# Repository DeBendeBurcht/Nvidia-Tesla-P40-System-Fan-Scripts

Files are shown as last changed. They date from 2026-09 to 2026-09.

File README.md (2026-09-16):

# 🌀 Nvidia Tesla P40 — System Fan Scripts

Control a **power-injected 9377 blower** (e.g. Delta BFB1012EH) from inside a Linux VM, through Proxmox, onto a motherboard `SYS_FAN` header.

Built for a **pasthrough NVIDIA Tesla P40 24GB** with a custom low-restriction shroud. Tuned and verified on **Proxmox VE** + **Debian 12**. The same ideas may work on other KVM setups with minor path tweaks.

---

> ⚠️ **Heads-up**  
> This repository was written with the help of AI. It is **not actively maintained**.  
> There is no support channel, no guaranteed compatibility matrix, and no promise that a future Proxmox / kernel / nvidia update will keep working without changes.  
>  
> That said — I'm proud of what this does on my box. Use it, fork it, break it, fix it. You own the risk on your own hardware.

---

## 🚨 Critical warnings (read before you touch hardware)

### 1. Set a **flat** BIOS fan curve first
If the host script is stopped, crashed, or not started yet, the motherboard reclaims the header. A normal BIOS “smart” curve will fight your last PWM write and can produce wild RPM swings.

**Do this in UEFI/BIOS before relying on the daemon:**

- Open the fan / hardware monitor page for the header you will use (`SYS_FAN2` in this project).
- Set a **flat fixed percentage** curve — not temperature-linked steps.  
  Example that works here: **20%** steady.
- Save and exit.

That way “script not running” = quiet, predictable airflow, not a roulette wheel.

### 2. Pick the **correct** fan header — wrong header can brick your calm
The host script writes directly to `pwmN` on the Super I/O chip (IT8689 via `it87`).

| Wrong move | What happens |
|---|---|
| `FAN_HEADER` points at CPU_FAN / a different SYS_FAN | You fight the BIOS or another controller on that channel |
| Two writers on the same `pwmN` (BIOS auto + script, or two scripts) | **Race condition** on the register — RPM hunting, odd ACPI behaviour, in the worst case a hard lock / crash loop |
| Power-injected blower on a header the board still tries to “sense” oddly | Noise, false tach, or surprise full speed |

**Checklist before `systemctl enable`:**

1. Physically plug the **BFB1012EH** (4-pin, molex +12V inject on the positive line — you already know that wiring is on you) into the intended header.
2. Confirm with `sensors` / sysfs which `hwmon*/pwmN` and `fanN_input` move when you twiddle that header.
3. Set `FAN_HEADER=N` in `gpu-fan-controller.sh` to **that** N only.
4. Do **not** leave the BIOS in “Smart” / “PWM auto” for that same header while the daemon owns it — use the flat % fallback from warning 1, and let the script switch `pwmN_enable` to manual while it runs.

### 3. Serial0 is exclusive
Guest talks to the host over QEMU `serial0` → guest `/dev/ttyS0`.

- Do **not** run `qm terminal <VMID>` on that serial while the fan bridge is up.
- Only **one** socket client at a time.

### 4. Guest “255” is a panic button
Host treats sustained **PWM 255** as “cooling failed → stop the VM”.  
Guest normal ceiling is **254**. Do not map a casual full-fan curve to 255.

---

## ✨ What this does

| Layer | Script | Job |
|---|---|---|
| **Proxmox host** | `gpu-fan-controller.sh` | Owns `SYS_FAN` via `it87`, reads PWM integers from the VM serial socket, applies hysteresis / heat-soak / fail-safes, writes sysfs |
| **Debian guest** | `gpu-fan-guest.sh` | Reads Tesla P40 die (and memory temp if the driver exposes it), util & power via `nvidia-smi`, runs a quiet fan curve + light prediction, heartbeats ASCII PWM lines to `/dev/ttyS0` |

### Goals on this machine
- Keep the **P40 stable and safe** under load  
- Keep the **server as silent as possible** at idle  
- Survive **VM crash / serial drop / script restart** without cooking the card or fighting the BIOS for minutes  

### Built-in safety (host)
| Event | Response |
|---|---|
| Guest silent ≥ **8s** (crash, hang, reboot) | Force **PWM 180** |
| VM offline | Idle **PWM 40**, then after **5 min** return header to **BIOS** |
| High duty then sudden drop | **Heat-soak** hold (~25s) so the heatsink can dump residual heat |
| Guest sends **255** for ~30s | `qm stop <VMID> --skiplock` |
| systemd restart while VM still up | Stay in **manual** at 180 — no 2s dive into the BIOS curve under a live P40 |

### Guest curve behaviour (defaults)
| State | Approx PWM |
|---|---|
| Idle ~40–50°C | 40–44 (near silent) |
| Light work ~60°C | ~78 |
| Real load ~70–75°C | ~145–180 |
| Hot ~84°C | ~240 |
| Normal max | **254** |
| Die ≥88°C held critical | **255** (host stop path) |

Light **prediction**: extra PWM when temperature is rising, SM util is already high while the die is still cool, or power draw is already elevated — so the 9377 leads the copper instead of chasing it. Asymmetric slew (`UP_STEP` / `DOWN_STEP`) stops the blower from yoyoing audibly.

---

## 🏗️ Architecture

```text
┌────────────────────────────────────────────────────────────┐
│  Proxmox VE host                                           │
│                                                            │
│  it87  →  /sys/class/hwmon/hwmonX/pwmN   (SYS_FAN header)  │
│                    ▲                                       │
│         gpu-fan-controller.sh                              │
│                    ▲                                       │
│         UNIX socket  /var/run/qemu-server/<VMID>.serial0   │
└────────────────────┼───────────────────────────────────────┘
                     │  QEMU serial0 (socket)
                     ▼
┌────────────────────────────────────────────────────────────┐
│  Debian 12 guest  (e.g. VM 126)                            │
│                                                            │
│  nvidia-smi  →  die °C · (mem °C) · util · power           │
│                    │                                       │
│         gpu-fan-guest.sh                                   │
│                    │                                       │
│         /dev/ttyS0   ASCII integer + newline, ≤8s heartbeat│
└────────────────────────────────────────────────────────────┘
```

**Fan path (physical):** Tesla P40 → custom shroud → Delta **BFB1012EH** (4-pin) → molex **+12V power inject** on the positive rail → motherboard **SYS_FAN** header (tach + PWM from the board, power from the PSU inject).

---

## 📦 Prerequisites

### Host (Proxmox VE)
- Working Proxmox install (verified idea on kernel family `6.8.x-pve`; yours may differ)
- Motherboard Super I/O supported by Frank Crawford’s **it87** DKMS (here: **IT8689** on a Gigabyte A520M-class board)
- Packages: kernel headers for the **running** kernel, `dkms`, `git`, `build-essential`, `lm-sensors`, **`netcat-openbsd`**
- Flat BIOS % on the target header (see warnings)

### Guest (Debian 12 VM)
- GPU **PCI passthrough** of the Tesla P40 working
- NVIDIA proprietary driver **535+** (`nvidia-driver`, `nvidia-smi` OK)
- `serial0: socket` on the VM config → `/dev/ttyS0` inside the guest

### Hardware notes
- **9377-size blower**, model used here: **BFB1012EH**
- Header-driven PWM + separate **power inject** (board header alone usually cannot feed this blower’s current)
- You are responsible for inject polarity, wire gauge, and not back-feeding the motherboard rail

---

## 🚀 Installation

### Part 1 — Proxmox host

#### 1️⃣ Kernel headers & tools
Pin to the kernel you are **actually booted on** (avoids pulling a newer headers package than your running image):

```bash
apt update
apt install -y pve-headers-$(uname -r) build-essential git dkms lm-sensors netcat-openbsd
```

#### 2️⃣ Frank Crawford `it87` via DKMS
```bash
cd /usr/src
git clone https://github.com/frankcrawford/it87.git
cd it87

# Only if a broken half-install exists from an old kernel:
# dkms remove it87/<old-version> --all 2>/dev/null || true

./dkms-install.sh
# or: dkms add . && dkms install it87/<version-shown-by-dkms>
```

#### 3️⃣ Persist the Gigabyte ACPI workaround (**both** files)
`modules-load.d` only takes the **module name**. Parameters belong in `modprobe.d`.

```bash
echo "it87" > /etc/modules-load.d/it87.conf
echo "options it87 ignore_resource_conflict=1" > /etc/modprobe.d/it87.conf
modprobe it87 ignore_resource_conflict=1
```

Confirm after reboot:

```bash
cat /sys/module/it87/parameters/ignore_resource_conflict   # expect Y or 1
lsmod | grep it87
sensors
```

#### 4️⃣ Find **your** fan header (do not skip)
```bash
# List chips / fans
sensors

# See which hwmon node is the IT8689 and which pwm/fan indices exist
grep -H . /sys/class/hwmon/hwmon*/name
ls /sys/class/hwmon/hwmon*/pwm* /sys/class/hwmon/hwmon*/fan*_input 2>/dev/null
```

Spin or stop the physical blower briefly (or watch RPM while changing BIOS % on one header only) until you know:

- `hwmon` path  
- `pwmN` / `fanN_input` index  

Set that index as `FAN_HEADER` in the host script. **Wrong N = race with something else on the board.**

#### 5️⃣ Attach QEMU serial0 to the GPU VM
```bash
qm set <VMID> --serial0 socket
# example: qm set 126 --serial0 socket
qm config <VMID> | grep serial0
```

#### 6️⃣ Install the host daemon
Copy `gpu-fan-controller.sh` to the host and adjust at least:

| Variable | Meaning | Example |
|---|---|---|
| `FAN_HEADER` | Motherboard header index (`pwmN`) | `2` |
| `VM_ID` | Proxmox VM id with the P40 | `126` |
| `PWM_IDLE` / `PWM_MIN` | Quiet floor while script owns the fan | `40` |
| `PWM_SAFE_FALLBACK` | Serial silence / takeover | `180` |

```bash
install -m 755 gpu-fan-controller.sh /usr/local/bin/gpu-fan-controller.sh
```

#### 7️⃣ systemd unit (host)
`/etc/systemd/system/gpu-fan-controller.service`:

```ini
[Unit]
Description=Proxmox Host SYS_FAN GPU Controller
After=pve-cluster.service qemu-server.service systemd-modules-load.service

[Service]
Type=simple
ExecStart=/usr/local/bin/gpu-fan-controller.sh
Restart=always
RestartSec=2s
TimeoutStopSec=8
StartLimitIntervalSec=60
StartLimitBurst=8

[Install]
WantedBy=multi-user.target
```

```bash
systemctl daemon-reload
systemctl enable --now gpu-fan-controller.service
journalctl -u gpu-fan-controller.service -f
```

Useful one-shot:

```bash
gpu-fan-controller.sh --status
```

---

### Part 2 — Debian guest (P40 VM)

#### 1️⃣ Serial node
```bash
ls -l /dev/ttyS0
```

#### 2️⃣ NVIDIA stack
```bash
sudo apt install -y nvidia-driver nvidia-kernel-dkms
nvidia-smi
nvidia-smi --query-gpu=temperature.gpu,temperature.memory,utilization.gpu,power.draw --format=csv,noheader
```

Die temperature should be a number. **Memory temp on P40 + 535 is often `[N/A]`** — the guest script treats that as optional and ignores it when missing.

#### 3️⃣ Install the guest reporter
Copy `gpu-fan-guest.sh`, then:

```bash
sudo install -m 755 gpu-fan-guest.sh /usr/local/bin/gpu-fan-guest.sh
```

Tune `GPU_T` / `GPU_P` (and optional `MEM_*`) if your shroud/ambient needs a quieter or colder curve. Leave **254** as the normal max unless you intend to trip the host emergency path.

#### 4️⃣ systemd unit (guest)
`/etc/systemd/system/gpu-fan-guest.service`:

```ini
[Unit]
Description=Tesla P40 Guest Fan Reporter
After=multi-user.target
# Optional if you use it:
# Wants=nvidia-persistenced.service

[Service]
Type=simple
ExecStart=/usr/local/bin/gpu-fan-guest.sh
Restart=always
RestartSec=2s

[Install]
WantedBy=multi-user.target
```

```bash
sudo systemctl daemon-reload
sudo systemctl enable --now gpu-fan-guest.service
sudo systemctl status gpu-fan-guest.service
sudo journalctl -u gpu-fan-guest.service -f
```

Guest status file (when running):

```bash
gpu-fan-guest.sh --status
# or: cat /dev/shm/gpu-fan-guest-state
```

---

## ✅ Validation checklist

### 1. Host driver & header
```bash
lsmod | grep it87
cat /sys/module/it87/parameters/ignore_resource_conflict
# Write a test value ONLY to the header you identified:
# echo 80 > /sys/class/hwmon/hwmonX/pwmN_enable   # 1 = manual
# echo 100 > /sys/class/hwmon/hwmonX/pwmN
# cat /sys/class/hwmon/hwmonX/fanN_input
```
Expect RPM to move on **that** blower only.

### 2. Guest is transmitting
```bash
sudo journalctl -u gpu-fan-guest.service -n 30 --no-pager
```
Expect lines with GPU °C, util, power, and outbound PWM. Heartbeat about every **2s**.

### 3. Host is applying
```bash
journalctl -u gpu-fan-controller.service -f
gpu-fan-controller.sh --status
```
Expect `ACTIVE`, PWM matching the guest (subject to hysteresis / heat-soak), non-zero RPM.

### 4. Forced ramp (acoustic test)
On the **guest**, temporarily raise the floor, then put it back:

```bash
sudo sed -i 's/^PWM_MIN=40/PWM_MIN=160/' /usr/local/bin/gpu-fan-guest.sh
sudo systemctl restart gpu-fan-guest.service
# blower should climb; host journal shows higher PWM / RPM
sudo sed -i 's/^PWM_MIN=160/PWM_MIN=40/' /usr/local/bin/gpu-fan-guest.sh
sudo systemctl restart gpu-fan-guest.service
```
After the drop, host **heat-soak** may hold an elevated duty ~25s — that is intentional.

### 5. Fail-safe smoke tests (careful)
| Test | Expect |
|---|---|
| `systemctl stop gpu-fan-guest` for >8s | Host → PWM **180** |
| Clean VM shutdown | Host → idle **40**, later BIOS after timeout |
| Stop host daemon with VM still up | Cleanup holds **180 manual** (not a surprise BIOS dip) |

---

## 🔧 Configuration map

### Host (`gpu-fan-controller.sh`)
| Knob | Role |
|---|---|
| `FAN_HEADER` | Sysfs `pwmN` / `fanN` index — **must match the physical header** |
| `VM_ID` | Proxmox VM id → `…/qemu-server/${VM_ID}.serial0` |
| `TIMEOUT_SEC` | Serial silence before safe fallback (default 8) |
| `PWM_IDLE` / `PWM_MIN` | Offline / clamp floor |
| `PWM_SAFE_FALLBACK` | Crash / silence / takeover |
| `HEAT_SOAK_*` | Post-load residual cooling |
| `BIOS_FALLBACK_TIMEOUT` | Seconds offline before `pwm_enable=2` |
| `HYSTERESIS_THRESHOLD` / `MIN_INTERVAL` | Anti-chatter + 1 Hz hardware write floor |

### Guest (`gpu-fan-guest.sh`)
| Knob | Role |
|---|---|
| `SERIAL` | Usually `/dev/ttyS0` |
| `INTERVAL_SEC` | Heartbeat (keep well under host `TIMEOUT_SEC`) |
| `GPU_T` / `GPU_P` | Die temperature curve |
| `MEM_T` / `MEM_P` | Used only if memory °C exists |
| `RISE_GAIN` / `UTIL_LEAD` / `POWER_LEAD_*` | Predictive boost |
| `UP_STEP` / `DOWN_STEP` | Audible smoothness |
| `CRIT_GPU_C` / `PWM_EMERGENCY` | Path to host VM stop |

---

## 🐛 Common pitfalls

| Symptom | Likely cause |
|---|---|
| `IT8689` / pwm not found | `it87` not loaded, or missing `ignore_resource_conflict=1` in **modprobe.d** |
| Fan flaps between two speeds | BIOS still on a smart curve for the **same** header, or wrong `FAN_HEADER` |
| Host stuck at 180 | Guest not heartbeating, bad `ttyS0`, or `qm terminal` stole serial0 |
| Guest write fails | VM has no `serial0: socket`, or wrong device node |
| `nc: invalid option -U` | Install **`netcat-openbsd`** (not traditional netcat only) |
| Memory temp always `-` | Normal on many P40 + 535 setups — die curve alone is enough |
| Server crashed after enable | **Wrong header** / dual control race — fix `FAN_HEADER`, set flat BIOS %, one writer only |

---

## 📁 Repo layout (suggested)

```text
.
├── README.md
├── host/
│   └── gpu-fan-controller.sh
└── guest/
    └── gpu-fan-guest.sh
```

Copy each script to `/usr/local/bin/` on the matching machine as shown above.

---

## 📄 License

GPL-2.0-style usage is fine for this tooling (same family as much of the kernel/DKMS stack you load beside it).  
No warranty. Full responsibility for hardware, wiring, power inject, and thermal outcome is yours.

---

## 🙏 Notes

- Written for **my** Ryzen + Gigabyte + Proxmox + Debian 12 + Tesla P40 + BFB1012EH path.  
- “Works on my machine” was earned the hard way (host IPC, heat-soak, BIOS fallback, guest curve).  
- If you publish a fork that survives another board or GPU, you are doing future strangers a favour — this repo itself may never track those variants.

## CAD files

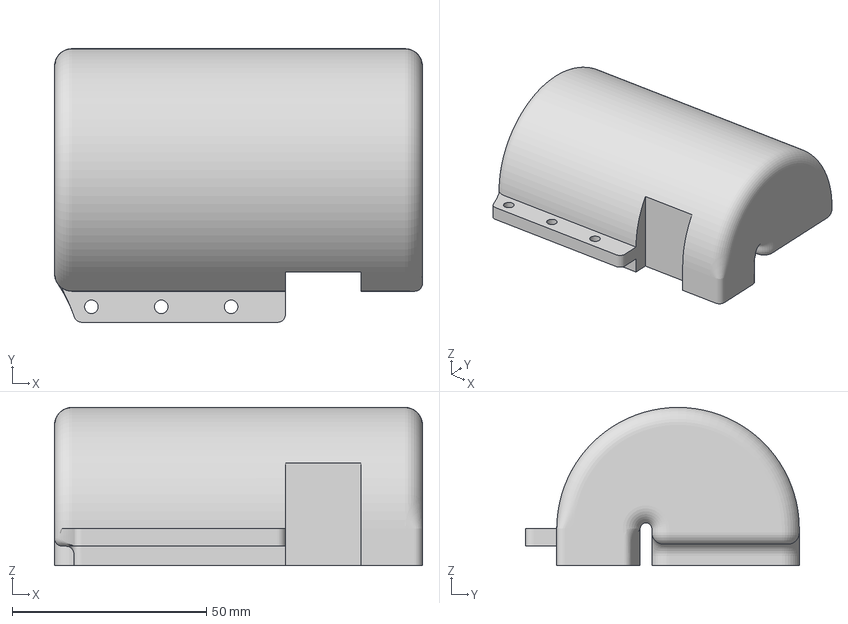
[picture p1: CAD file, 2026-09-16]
Fan Shroud Nvidia P40.3mf
94.8 x 70.5 x 40.8 mm

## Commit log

2026-09-16 Add gpu-fan-controller.sh for GPU fan management
    This script controls the GPU fan on a Proxmox VE host, managing PWM based on guest input and system conditions.
2026-09-16 Add GPU fan controller script for Tesla P40
    This script monitors the Tesla P40 GPU temperature and adjusts the fan speed accordingly via PWM over a serial connection. It includes safety features for overheating and ensures smooth transitions in fan speed.
2026-09-16 Decrease minimum PWM value from 40 to 20
2026-09-16 Enhance README with installation and validation steps
    Expanded README with detailed installation and validation instructions for Proxmox GPU fan control.
2026-09-16 Rename Fan Shroud Nvidia Tesla P40 24gb with 9733 size blower.3mf to Fan Shroud Nvidia P40.3mf
    [Fan Shroud Nvidia P40.3mf]
